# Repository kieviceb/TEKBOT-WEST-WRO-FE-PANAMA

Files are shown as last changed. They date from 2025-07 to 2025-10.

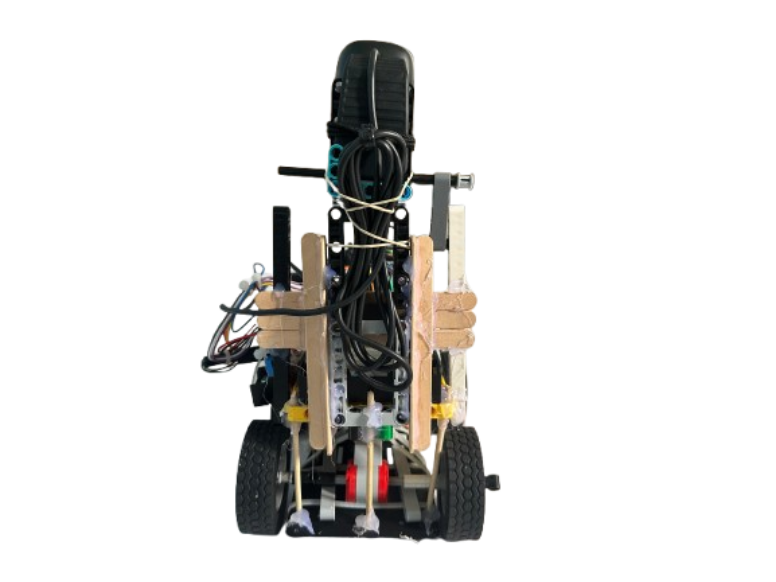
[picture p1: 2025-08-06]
vehicle photos/BACK HAM.png

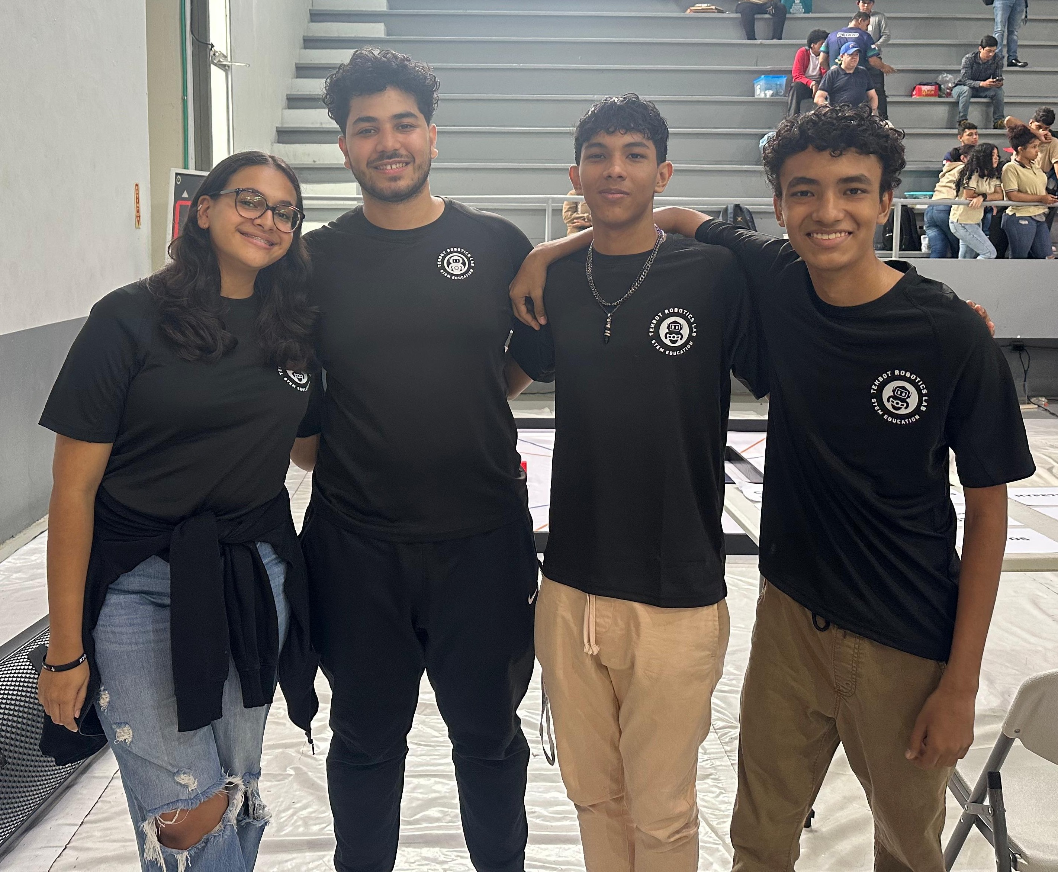
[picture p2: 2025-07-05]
team photos/TEAM PHOTOOOO.jpg

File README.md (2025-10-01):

# TEKBOT WEST's readme Bandera de Panamá
<p align="center">
  TEKBOT (1)
</p>




> [!NOTE] 
> This github repository contains many illustrative content such as images,
> gifs and video, so wait till is fully refresh to see it in its entirety.  
> 
# 🐙 Repo's folder structure/overview
```
📦 TEKBOT-WEST-WRO-FE
├── 📁 3D_printables # 3D models ready for printing robot components
├── 📁 MACHINE LEARNING MODEL # contains the trained model for the CORAL accelerator
├── 📁 schemes # Wiring and schematic diagram
├── 📁 src # Source code for robot control and challenge algorithms
├── 📁 team photos # Photos of the team 
├── 📁 vehicle photos # Pictures of the robot at different views
├── 📁 video # Video of testing competition runs
├── 📄 README.md # Main project documentation
```
---

AHHHHH_processed_by_imagy
<a href="https://github.com/kieviceb/TEKBOT-WEST-WRO-FE-PANAMA/tree/main/team%20photos">
  BEHIND THE SCREENS (2)
</a>

---
# Vehicle Photos 📸
<p align="center">
  TEKBOT (1)
</p>

Copia de BEHIND THE SCREENS

# Components 🧱
A list of all the electrical and mechanical components on the robot.

|  |  |  | 
| :---: |:---:| :---:|
|[RASPBERRY PI 5 - 8GB RAM x1](https://a.co/d/7e9fzE2)|[MICROSOFT LIFECAM HD-3000 x1](https://a.co/d/66cNAOh)|[L298N MOTOR DRIVER x1](https://www.steren.com.pa/tarjeta-para-control-de-motores-cc-l298n.html)|
|  |  |  |
|[ARDUINO NANO RP2040 CONNECT x1](https://a.co/d/hI8sZ40) |[FUNDUINO KIT CHASSIS x1](https://a.co/d/fpJSHg1)|[GEEKWORM X1202 4-Cell 5V UPS Shiled+Active Cooler H505 x1](https://a.co/d/hs9rgxH) |
|  ||  |
|[JUMPER WIRES](https://a.co/d/cw9IdJk)|[MG996R METAL GEAR SERVO x1](https://a.co/d/cRVAc0u)|[STEREN Li-ion 2800 mAh RRECHARGABLE BATTERY x7](https://www.steren.com.pa/bateria-recargable-li-ion-2800-mah-tipo-18650-1.html)|
|  ||  |
|[ULTRASONIC DISTANCE SENSOR x3](https://a.co/d/cxbABTR)|[LEGO EV3 DC MOTOR](https://ebay.us/m/6vxrYN)|[COOLING FAN x3](https://a.co/d/frwMkoA)|
|  ||  |
|[MINI BREADBOARD x1](https://a.co/d/0logMX9)|[PUSH BUTTON x1](https://a.co/d/70cfCgl)|[10K OHM RESISTOR x1](https://a.co/d/dTNRWBD)|

THE MAGIC
| :------------: |
|  |
|[GOOGLE CORAL USB EDGE TPU ACCELARATOR x1](https://a.co/d/eEklwQk)|

# ⚡Circuit diagram

Wiring diagram

# Future Engineers Challenge Overview

The **WRO 2025 Future Engineers challenge** challenges teams to design and build a fully autonomous robot capable of navigating a dynamic and randomized racetrack. Using a combination of sensors, computer vision, and advanced control algorithms, the robot must adapt to changing obstacles, follow predefined driving rules, and demonstrate precise maneuvering skills.

### 📌 Competition Format

- **🏁 Open Challenge:**  
  The robot must complete **three (3) laps** around a track where obstacles and track elements are randomly placed, requiring real-time adaptation.

- **🚦 Obstacle Challenge:**  
  The robot must detect and respond correctly to randomly positioned colored markers:  
  - 🟥 **Red signs** → Robot must drive on the right side of the lane.  
  - 🟩 **Green signs** → Robot must drive on the left side of the lane.

  After completing the laps, the robot must find a designated parking zone and perform a precise **parallel parking maneuver** within a confined space, adding an additional technical challenge.

### 📑 Documentation Requirements

Each team is required to maintain a **public GitHub repository** documenting their engineering design process, technical decisions, robot design, and source code. This encourages transparency, collaboration, and learning within the robotics community.

### 🏆 Scoring & Evaluation

Teams are evaluated based on their robot’s **accuracy**, **speed**, and the quality of their **technical documentation**. Points are awarded to teams that effectively balance performance, adaptability to randomized conditions, and innovation in their approach. This challenge promotes not only technical skills in robotics and programming but also problem-solving, teamwork, and creative engineering.
> [!WARNING]
>
> We noticed a translation misunderstanding regarding the rules, at the original english version it says
> that the robot starting within the parking lot is 7 points, but in the spanish version states that the robot should be on
> In the parking lot, not specifying if before or after the challenge is done, but taking as reference the original english version
> the robot starting on the parking lot can score 7 points.
>
meet the team (3)

---

> [!NOTE]
> For detailed rules and regulations (PANAMA ONLY), please refer to the official WRO Panama 2025 Future Engineers document:  
> [WRO 2025 Future Engineers Rules (PDF)](https://fundesteam.nyc3.cdn.digitaloceanspaces.com/FutureEngineers/WRO-2025-FE-Reglas%20Generales.pdf)

<br>

# ⚙️ Mobility Management

### Movement
- **LEGO EV3 DC Motor** driven by an L298N H-bridge on the Arduino Nano RP2040, powered by a 3×18650 Li-ion pack (≈11.1 V) for high torque.
- PWM speed control (pin D3) and direction pins (D4/D5), with automatic halt if HC-SR04 front distance < threshold.
- Receives speed & direction commands over Serial1 from the Raspberry Pi.

### Steering
- **MG996R metal-gear servo** in an Ackermann linkage for accurate, repeatable turns (pin D2).
- Servo angles (20° left, 90° center, 155° right) sent as ASCII strings over Serial1 and output via PWM.

# 🔋 Power Management

Our robot uses a streamlined power system for stable, efficient energy distribution:

- **Geekworm UPS Module**  
  All computing units (Raspberry Pi & Arduino Nano RP2040) are powered directly from the Geekworm Raspberry Pi Wide Input Voltage UPS, providing regulated 5 V output and battery backup—no external power bank needed.

- **Servo Power**  
  The MG996R steering servo draws its 5 V supply from the UPS module, ensuring stable, synchronized operation.

- **Camera and CORAL accelerator Power**  
  The Microsoft LifeCam HD-3000 and the CORAL connect via USB to the Raspberry Pi and is powered through the UPS, eliminating separate power sources.

- **DC Motor Power**  
  The L298N H-bridge and DC motor are driven by a dedicated pack of three 18650 Li-ion cells in series (≈11.1 V), delivering the higher voltage and current the motor requires.

This setup guarantees reliable power under all operating conditions.  

# 📡 Robot Communication

Our robot implements a structured communication system between its two core processing units to ensure synchronized and reliable operation:

- The **Raspberry Pi** (SBC – Single Board Computer) acts as the **master**. It is responsible for high-level tasks such as image processing, object detection, strategy decision-making, and general system coordination.

- The **Arduino Nano RP2040** (SBM – Secondary Board Microcontroller) acts as the **slave**. It is dedicated to real-time control of low-level hardware components, such as driving the servo motor, ultrasonic sensors, LEGO EV3 DC MOTOR and interpreting incoming instructions from the master.

### 🔁 Serial Communication

The two boards communicate via a **UART (Serial) interface** using the following configuration:

- **Raspberry Pi TX (GPIO 14)** → **Arduino RX (pin 1)**  
- **Raspberry Pi RX (GPIO 15)** ← **Arduino TX (pin 0)**

This full-duplex serial link enables:

- The **Raspberry Pi (master)** to send instructions like servo angles or movement triggers based on camera input.
- The **Arduino (slave)** to receive commands and execute precise control over hardware.
- **Optional feedback**: The Arduino can also send status messages or sensor feedback back to the Raspberry Pi when necessary.

This master-slave architecture promotes:

- **Modularity**, by separating high-level logic and low-level control.
- **Responsiveness**, with real-time actions handled by the microcontroller.
- **Scalability**, allowing for future hardware expansions without major rewrites.

The system is optimized for efficiency and robustness in fast-paced robotic challenges.

# 👁️ Sense and Object Detection

Our robot relies on a combination of vision (OpenCV + ML on Coral Accelerator) and ultrasonic sensing to understand its environment and make driving decisions.

## Vision System

<p align="center">
  Dataset samples
</p>

- We use the Microsoft LifeCam HD-3000 connected to the Raspberry Pi. The Pi processes the camera feed with OpenCV and a Machine Learning model accelerated by Coral to:
- Detect red and green blocks for obstacle avoidance.
- Recognize the magenta parking spot to initiate the parking routine.
- Detect black walls and estimate their distance.
- Send steering and speed commands to the Arduino Nano RP2040 over Serial.

## Ultrasonic Distance Sensing

<p align="center">
  Dataset samples
</p>

- The Arduino Nano RP2040 reads three HC-SR04 ultrasonic sensors (left, center, right) to:
    - Measure the robot’s distance from the walls.
    - Detect obstacles that may not be visible to the camera.
    - Provide redundancy and safety in case of vision failure.
    - This multi-sensor approach ensures robust performance:
    - Vision + ML handles colored block detection, parking, and wall recognition.
    - Ultrasonics provide accurate distance measurements for safety and redundancy.
      
## Machine Learning  

To improve robustness, we trained a **custom object detection model** specifically for our robot’s environment.  

<p align="center">
  Dataset samples
</p>

- The dataset was built using **Roboflow** 👉 our data set [here](https://universe.roboflow.com/tekbot-west/tekbot-west-nacional-bbbm9/dataset/2).  
- We collected and labeled images of **green/red blocks, walls, and parking spots** at different **distances, angles, and lighting conditions**, to ensure stable detection during competition with minimal calibration.  

<p align="center">
  YOLOv8 Training
</p>

- The model uses the **YOLOv8 format**, which is well-suited for real-time detection thanks to its **lightweight architecture and speed** — ideal for embedded systems.  
- Training was done in **Google Colab** using GPU acceleration.  
- Finally, we exported the trained model to **TensorFlow Lite**, optimized for the **Coral Edge TPU accelerator** on the Raspberry Pi.  

This pipeline allows the robot to run **real-time detection with low latency**, ensuring reliable navigation and obstacle avoidance.  

# ⚔️ Challenge Strategies
## Open Challenge Strategy 
- **Start Command**  
  When button is start button is pressed on the Raspberry pi sends `'s'` on Serial1 before beginning navigation.

- **Ultrasonic Sensing**  
  Continuously read left, center and right HC-SR04 sensors for obstacle distances.

- **Front Obstacle Handling**  
  If center distance ≤ FRONT_MIN, halt motor; otherwise drive at fixed PWM speed.

- **Emergency Side Avoidance**  
  If left or right distance ≤ SIDE_MIN, immediately steer hard away (servo to 150° or 20°).

- **PD Steering Control**  
  When no emergency, compute error = dR − dL and derivative, apply Kp/Kd to adjust servo within +60° -70° o deadzone around 90°.  
  This ensures smooth alignment between the two side walls.

- **Lap Counting via Encoder**  
  The IMU is no longer used. Instead, we rely on the wheel encoder:  
  - Calibration showed that **10,000 encoder counts ≈ 30 cm of travel**.  
  - Since each lap around the track is ~2 m, that corresponds to ~66,667 encoder counts.  
  - Running multiple trials from different start positions, we computed a **median value** for 3 laps.  
  - The robot stops when the encoder reading reaches this median threshold, ensuring reliable lap counting independent of curves.

- **Completion Condition**  
  Stop motor and center servo once the encoder threshold for 3 laps is reached; remain halted.

- **Serial Feedback**  
  Print encoder values, lap progress, and status messages over Serial1 for real-time monitoring.

## Obstacle Challenge Strategy 
- **Start & Exit Detection**  
  At the beginning, the robot uses **ultrasonic sensors** to measure wall distances and determine **which side it exits from the parking area**.  
  This defines its initial orientation on the track.

- **Machine Learning Object Detection**  
  Instead of simple LAB masking, we use a **YOLOv8-based model** (dataset and labels in Roboflow, trained in Google Colab and exported to TensorFlow Lite, and accelerated with Coral).  
  The model detects **red blocks, green blocks, black walls, and the magenta parking zone** in real time.  

- **Block Evasion Strategy**  
  When a block is detected:  
  - **Red →** compute a temporary target position **to the right side** and steer the robot to bypass the block.  
  - **Green →** compute a temporary target position **to the left side** for evasion.  
  The robot continues toward this evasion target until the block is cleared, then smoothly returns to its central trajectory.  

- **Lap Counting via Parking Detection**  
  Instead of counting curves or encoder ticks, the robot uses **ML detection of the magenta parking spot** as a lap marker.  
  - Each time the robot passes the parking, the counter increases by **1 lap**.  
  - After **3 passes (3 laps)**, the robot transitions to the final parking stage.  

- **PD Steering Control**  
  During normal navigation, the robot still uses **PD control** based on ultrasonic side distances (`dR - dL`) to stay centered in the lane, ensuring smooth driving even without visible blocks.  

- **Final Parking Routine**  
  Once 3 laps are completed, the robot searches for the **magenta parking zone** using ML detection.  
  Upon recognition, it executes a **parallel parking maneuver**, aligning itself precisely inside the designated parking spot.  

- **Serial Communication**  
  All steering (`S<angle>`) and motor commands are sent from the Raspberry Pi to the Arduino Nano via Serial, ensuring synchronized control.

# `</>` Into the codes (code explanations)

## 1. **Open Challenge Code — Main loop (core)**
> To keep this README concise, here we only explain the **main loop** (the core logic).  
> A complete explanation and all helper functions can be found in the [`/src`](./src) folder.  

```cpp
void loop() {

  if (!started) {
    if (Serial1.available() && Serial1.read() == 's') { //button pressed on raspberry pi sends the command to start
      started = true;
      Serial1.println("Starting navigation…");
      prevTime = micros();       // reset PD timing
      prevError = 0;
    } else {
      return;                    // stay idle until 's' is received
    }
  }
```
-  Wait for the start command over Serial1 ('s')
```cpp
 
  float dL = readUltrasonic(TRIG_LEFT,  ECHO_LEFT);   // left wall/obstacle
  float dC = readUltrasonic(TRIG_CENT,  ECHO_CENT);   // front obstacle
  float dR = readUltrasonic(TRIG_RIGHT, ECHO_RIGHT);  // right wall/obstacle

  // C) Front obstacle handling: stop if too close, otherwise run motor at fixed PWM
  if (dC <= FRONT_MIN) {
    analogWrite(ENB, 0);                 // stop motor
  } else {
    analogWrite(ENB, MOTOR_SPEED);       // forward at constant speed
  }
```
- Read distances (cm) from the 3 HC-SR04 ultrasonic sensors
```cpp
  if (dL <= SIDE_MIN_LEFT) {
    steeringServo.write(SERVO_MAX_RIGHT);  // steer right
  }
  else if (dR <= SIDE_MIN_RIGHT) {
    steeringServo.write(SERVO_MAX_LEFT);   // steer left
  }
  else {
```
 - Emergency side avoidance: steer hard away if a wall is too close
```cpp
    unsigned long now = micros();
    float dt = (now - prevTime) / 1e6;     // seconds
    prevTime = now;

    float error = dR - dL;                  // if dR>dL → robot is too close to left wall
    float dErr  = (error - prevError) / max(dt, 1e-3f);
    prevError   = error;

    int delta = constrain(int(Kp*error + Kd*dErr), -SERVO_DEADZONE, SERVO_DEADZONE);
    steeringServo.write(SERVO_CENTER + delta);  // adjust steering within limits
  }
```
- PD control for smooth centering when no emergency
```cpp
  if (encoderTicks >= ENCODER_3LAPS) {
    analogWrite(ENB, 0);                   // stop motor
    steeringServo.write(SERVO_CENTER);     // center steering
    Serial1.println("3 laps (median) reached — stopping.");
    while (true) { /* halt */ }            // end of challenge
  }
```
- Lap counting using the encoder 
Calibration: 10,000 ticks ≈ 30 cm → 1 lap (~2.0 m) ≈ 66,667 ticks
3 laps ≈ ~200,000 ticks. After several trials we set ENCODER_3LAPS to the median value.
 (encoderTicks is updated in the ISR or encoder routine outside this loop.)

## 2. **Obstacle Challenge code**

```python
ok, frame = cap.read()
if not ok:
    continue

Hf, Wf = frame.shape[:2]
y_min  = int(ROI_Y_MIN_RATIO * Hf)
x_l    = int(ROI_X_MARGIN * Wf)
x_r    = int((1.0 - ROI_X_MARGIN) * Wf)
```
read a frame and prepare ROI bands (bottom-focused + side margins)
Grab the camera frame and compute the active ROI: ignore the top band and a small margin on both sides to reduce false triggers and focus on near-field decisions.

```python
rgb = cv2.cvtColor(frame, cv2.COLOR_BGR2RGB)
inp = cv2.resize(rgb, (in_w, in_h), interpolation=cv2.INTER_LINEAR)
```
preprocess and run YOLOv8 (EdgeTPU) inference
```python
_interpreter.set_tensor(_input_details[0]['index'], np.expand_dims(inp, 0))
_interpreter.invoke()
out0 = _interpreter.get_tensor(_output_details[0]['index'])
dets = parse_yolov8_tflite(out0, _output_details[0], Wf, Hf, CONF_THRESH, NMS_IOU, _labels)
```
Convert to RGB, resize to model input, invoke TFLite + EdgeTPU, then parse outputs (dequantize, class scores, NMS) into frame-space detections.

```python
valid_L = valid_R = False
has_pklot = False

for d in dets:
    x, y, w, h, name = d['x'], d['y'], d['w'], d['h'], d['name']
    cx, cy = x + w//2, y + h//2

    in_roi = (cy >= y_min) and (x >= x_l) and (x + w <= x_r)
    near   = (cy >= int(NEAR_Y_RATIO * Hf))

    if not in_roi:
        continue

    if name == CLASS_GBLOCK and near:
        valid_L = True    # green → plan left bypass
    elif name == CLASS_RBLOCK and near:
        valid_R = True    # red → plan right bypass
    elif name == CLASS_PKLOT:
        has_pklot = True  # parking marker seen
```
scan detections to set intent flags (valid_L/valid_R) and see PKLOT
For each detection: check ROI and near-field; flag left/right evasion intent from block color; flag PKLOT for lap counting.

```python
now = time.time()
if has_pklot and (now - pklot_last_seen_t) > PKLOT_DEBOUNCE_SEC:
    pklot_last_seen_t = now
    pklot_count += 1
    if (pklot_count >= PKLOT_TARGET_COUNT) and not parking_mode:
        parking_mode = True
        if ser: ser.write(b"PARK\n")
```
debounced PKLOT counting; switch to PARK after N passes
Use a debounce window to avoid multiple counts per pass; after 3 PKLOT sightings, enter PARK mode and notify the Arduino.

```python
cooldown_ok = (now - last_cmd_t) >= COOLDOWN_SEC
streak_L = streak_L + 1 if valid_L else 0
streak_R = streak_R + 1 if valid_R else 0

send_L = cooldown_ok and (streak_L >= TRIGGER_FRAMES) and not parking_mode
send_R = cooldown_ok and (streak_R >= TRIGGER_FRAMES) and not parking_mode

if send_L or send_R:
    cmd = "PATH L" if send_L else "PATH R"
    if ser: ser.write((cmd + "\n").encode("ascii"))
    last_cmd_t = now
    streak_L = streak_R = 0
```
PATH decision: cooldown + streak of valid frames
Require a minimum streak of consecutive frames before acting, and enforce a cooldown so you send only one high-level command (PATH L/PATH R) per window. Suppress PATH when already in PARK mode.

```python
if SEND_STEER_TOWARD_WAYPOINT and aim_points:
    aim_x, aim_y = aim_points[-1]             # latest proposed lateral pass point
    sdeg = steer_towards_x(aim_x, Wf)         # map lateral error to servo [0..180]
    if ser: ser.write(f"S {sdeg}\n".encode("ascii"))
```
(optional) send direct steering toward lateral waypoint
Optionally bias steering directly toward the computed waypoint beside the block; main evasion still uses PATH L/R.

```python
cv2.line(frame, (0, y_min), (Wf, y_min), (255,255,0), 1)
cv2.rectangle(frame, (x_l, 0), (x_r, Hf), (255,255,0), 1)
cv2.putText(frame, f"PKLOT:{pklot_count}  MODE:{'PARK' if parking_mode else 'RUN'}",
            (6, Hf-8), cv2.FONT_HERSHEY_SIMPLEX, 0.6, (0,255,255), 2)

cv2.imshow("Coral YOLOv8 -> Serial", frame)
if (cv2.waitKey(1) & 0xFF) == ord('q'):
    break
```
overlays & exit handling
Draw ROI and status overlays; show the preview; quit cleanly on q.

```python
if ser:
    ser.write(b"STOP\n")
    ser.close()
cap.release()
cv2.destroyAllWindows()
```
on exit: stop and cleanup
Send a final STOP, close serial and camera, destroy windows.

## 3. **Servo control code**

- Setup function
```ino
void setup() {
  miServo.attach(pinServo);
  Serial1.begin(9600);
  Serial.begin(9600);
  delay(1000);

  Serial.println("Send angle (0 to 180) via Serial1 to move the servo.");
  miServo.write(90);
}
```
The servo is attached to the specified pin. UART serial communication (Serial1) is started at 9600 baud to talk with the Raspberry Pi, and USB serial (Serial) is started for debugging. The program waits one second for stability. A message with instructions is printed to the debug monitor. The servo is initialized at center position (90 degrees).

- Loop function: reading and processing commands
```ino
void loop() {
  while (Serial1.available() > 0) {
    char c = Serial1.read();

    if (c == '\n' || c == '\r') {
      comando.trim();

      if (comando.length() > 0) {
        int angulo = comando.toInt();

        if (angulo >= 0 && angulo <= 180) {
          miServo.write(angulo);
          Serial.print("Servo moved to ");
          Serial.print(angulo);
          Serial.println(" degrees");
        } else {
          Serial.println("Angle out of range (0–180)");
        }
      }

      comando = "";
    } else {
      comando += c;
    }
  }
}
```
The code reads incoming characters from the UART serial buffer one by one. It accumulates them into a command string until it detects a newline or carriage return character, signaling the end of a command. Then it trims whitespace from the command. If the command is not empty, it converts the string to an integer representing the servo angle. It checks if the angle is between 0 and 180 degrees. If valid, it moves the servo to that angle and prints a confirmation message. If invalid, it prints an error message. After processing, it clears the command buffer to prepare for the next command and continues looping.

## 4. **Run code when the raspberry turns on**
- Import libraries and modules
```python
from gpiozero import Button
from signal import pause
import subprocess
```
The script imports the Button class from gpiozero to handle GPIO pin inputs on the Raspberry Pi. The pause function from the signal module is imported to keep the script running and listening for events. The subprocess module allows the script to run external programs or scripts.

- Initialize button on GPIO pin 16
```python
boton = Button(16)
```
A Button object is created and linked to GPIO pin 16, which is physically connected to a push button on the Raspberry Pi. This button will trigger running the robot’s main program.

- Define function to run the main program
```python
def ejecutar_programa():
    print("Button pressed! Running the main program...")
    subprocess.run(["python3", "/home/frankie/WRO_Ingeniero/execute.py"])
```
This function runs when the button is pressed. It prints a message to the terminal indicating the button press and then uses subprocess.run to execute another Python script (otracosaahi.py), which is the robot’s main control program. The path must be correct and the script must be executable.

- Link button press event to the function
```python
boton.when_pressed = ejecutar_programa
```
The button’s press event is connected to the ejecutar_programa function. When the button is pressed, this function will be called automatically.

- Indicate readiness and keep script running
```python
print("Waiting for the button to be pressed...")
pause()
```
Prints a message to inform the user that the system is ready and listening for the button press. The pause() function keeps the script running indefinitely so it can detect the button press event; without it, the script would exit immediately.

# 🎥 Video demonstration
TEKBOT (https://youtu.be/VGku5C4htFQ?si=9HICP8p2Be4NuSKb)
TEKBOT(2) (https://youtu.be/uQNMZddFvvI?si=1SfpjZH-YJ5O9Mvj)
---
**Stay tuned for updates as we continue to improve our robot's performance and capabilities!**

# References
- https://docs.ultralytics.com/models/yolov8/
- https://colab.research.google.com/github/roboflow/notebooks/blob/main/notebooks/train-yolov8-object-detection-on-custom-dataset.ipynb
- https://nerdvana.ro/wro-fe/
- https://markdownlivepreview.com/
- https://docs.opencv.org/3.4/da/d97/tutorial_threshold_inRange.html

# Shout-Outs

A huge thank you to everyone who made this project possible:

- **The Sutherland Family**  
  For sharing their technical know-how, sourcing crucial parts, and helping with all of our 3D printing needs.

- **Ericka’s Family**  
  For opening up their living room as our track space and pitching in to build the surrounding walls.

- **The Hidalgo Family**  
  For generously donating the printed track mat that serves as our competition surface.

- **Diego’s Family**  
  For welcoming us into their home and providing a comfortable space for our team meetings and build sessions.

We couldn’t have done it without your support—thank you for being an integral part of our journey!

# 📜 License

MIT License

Copyright (c) 2025 Ericka Ceballos

Permission is hereby granted, free of charge, to any person obtaining a copy
of this software and associated documentation files (the "Software"), to deal
in the Software without restriction, including without limitation the rights
to use, copy, modify, merge, publish, distribute, sublicense, and/or sell
copies of the Software, and to permit persons to whom the Software is
furnished to do so, subject to the following conditions:

The above copyright notice and this permission notice shall be included in all
copies or substantial portions of the Software.

THE SOFTWARE IS PROVIDED "AS IS", WITHOUT WARRANTY OF ANY KIND, EXPRESS OR
IMPLIED, INCLUDING BUT NOT LIMITED TO THE WARRANTIES OF MERCHANTABILITY,
FITNESS FOR A PARTICULAR PURPOSE AND NONINFRINGEMENT. IN NO EVENT SHALL THE
AUTHORS OR COPYRIGHT HOLDERS BE LIABLE FOR ANY CLAIM, DAMAGES OR OTHER
LIABILITY, WHETHER IN AN ACTION OF CONTRACT, TORT OR OTHERWISE, ARISING FROM,
OUT OF OR IN CONNECTION WITH THE SOFTWARE OR THE USE OR OTHER DEALINGS IN THE
SOFTWARE.

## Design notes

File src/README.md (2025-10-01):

## 1. **Open Challenge code**
```ino
#include <Servo.h>  // Include the Servo library to control a hobby servo motor

// —— ULTRASONIC SENSOR PINOUT ——  
// These pins are connected to three ultrasonic distance sensors: left, center, and right
const int TRIG_LEFT   = 6;   // Trigger pin for the left ultrasonic sensor
const int ECHO_LEFT   = 7;   // Echo pin for the left ultrasonic sensor
const int TRIG_CENT   = 8;   // Trigger pin for the center ultrasonic sensor
const int ECHO_CENT   = 9;   // Echo pin for the center ultrasonic sensor
const int TRIG_RIGHT  = 10;  // Trigger pin for the right ultrasonic sensor
const int ECHO_RIGHT  = 11;  // Echo pin for the right ultrasonic sensor

// —— ACTUATOR PINOUT ——  
// Pins to control the servo (steering) and a motor (via H-bridge L298N)
const int SERVO_PIN      = 2;   // Servo control pin
const int ENB            = 3;   // Motor speed pin (PWM)
const int IN3            = 4;   // Motor direction pin
const int IN4            = 5;   // Motor direction pin

// —— CONTROL PARAMETERS (PD controller) ——  
const float Kp           = 0.5;   // Proportional gain for PD control
const float Kd           = 0.1;   // Derivative gain for PD control
float prevError          = 0;     // Previous error value for derivative calculation
unsigned long prevTime   = 0;     // Previous time in microseconds for derivative calculation

// —— SAFETY THRESHOLDS IN CM ——  
const float SIDE_MIN_LEFT   = 17.0;  // Minimum allowed distance on left side
const float SIDE_MIN_RIGHT  = 18.5;  // Minimum allowed distance on right side
const float FRONT_MIN       = 25.0;  // Minimum allowed distance in front

// —— SERVO LIMITS ——  
const int SERVO_CENTER      = 90;   // Center position of servo (straight)
const int SERVO_MAX_LEFT    = 20;   // Maximum left steering angle
const int SERVO_MAX_RIGHT   = 150;  // Maximum right steering angle
const int SERVO_DEADZONE    = 60;   // Maximum deviation allowed for PD output

// —— FIXED MOTOR SPEED ——  
const int MOTOR_SPEED       = 200;  // PWM value for motor speed (0–255)

Servo steeringServo;  // Create Servo object for steering

// ==================== ENCODER SETUP ====================
// Pins for quadrature encoder
const uint8_t ENC_B = 12;   // Encoder channel B
const uint8_t ENC_A = 13;   // Encoder channel A

volatile long encoderCount = 0;    // Counter for encoder ticks (volatile because updated in ISR)
volatile uint8_t prevAB = 0;       // Previous state of encoder channels

// Quadrature table for determining rotation direction
int8_t quad_table[16] = {
  0, -1, +1,  0,
  +1, 0,  0, -1,
  -1, 0,  0, +1,
   0, +1, -1,  0
};

const long STOP_COUNTS = 2000;  // Encoder count at which the robot must stop

// Helper function to read current state of encoder channels A and B
inline uint8_t readAB() {
  return (digitalRead(ENC_A) << 1) | (digitalRead(ENC_B));
}

// Interrupt service routine (ISR) for encoder updates
void isr_any() {
  uint8_t curr = readAB();               // Read current encoder state
  uint8_t idx  = ((prevAB << 2) | curr) & 0x0F; // Combine previous and current state
  encoderCount += quad_table[idx];       // Update encoder count according to table
  prevAB = curr;                         // Store current state for next ISR
}
// =================================================

// —— START FLAG ——  
bool startFlag = false;  // Flag to indicate when robot should start moving

void setup() {
  // —— ENCODER SETUP ——  
  pinMode(ENC_A, INPUT_PULLUP);  // Enable internal pull-up resistor
  pinMode(ENC_B, INPUT_PULLUP);  // Enable internal pull-up resistor
  prevAB = readAB();             // Initialize previous state
  attachInterrupt(digitalPinToInterrupt(ENC_A), isr_any, CHANGE); // Interrupt on channel A
  attachInterrupt(digitalPinToInterrupt(ENC_B), isr_any, CHANGE); // Interrupt on channel B

  // —— ULTRASONIC SENSOR SETUP ——  
  pinMode(TRIG_LEFT,   OUTPUT);
  pinMode(ECHO_LEFT,   INPUT);
  pinMode(TRIG_CENT,   OUTPUT);
  pinMode(ECHO_CENT,   INPUT);
  pinMode(TRIG_RIGHT,  OUTPUT);
  pinMode(ECHO_RIGHT,  INPUT);

  // —— SERVO AND MOTOR SETUP ——  
  steeringServo.attach(SERVO_PIN);       // Attach servo object to pin
  steeringServo.write(SERVO_CENTER);     // Initialize servo to center position

  pinMode(ENB, OUTPUT);                  // Motor speed control
  pinMode(IN3, OUTPUT);                  // Motor direction
  pinMode(IN4, OUTPUT);                  // Motor direction
  digitalWrite(IN3, HIGH);               // Set initial direction forward
  digitalWrite(IN4, LOW);

  prevTime = micros();                   // Initialize timing for PD derivative

  // —— SERIAL COMMUNICATION ——  
  Serial1.begin(115200);   // Serial1 for Raspberry Pi communication
  Serial.begin(115200);    // USB serial for debugging
  while (!Serial) {}       // Wait for serial port to be ready
  Serial.println(F("System ready, waiting for 's' from RPi..."));
}

void loop() {
  // —— SERIAL1 LISTENING ——  
  if (Serial1.available()) {
    char cmd = Serial1.read();  // Read command from Raspberry Pi
    if (cmd == 's') {           // If 's' is received, start robot
      startFlag = true;
      encoderCount = 0;         // Reset encoder when starting
      Serial.println(F("✔ Start received from RPi"));
    }
  }

  // —— WAIT FOR START FLAG ——  
  if (!startFlag) {
    analogWrite(ENB, 0);              // Stop motor
    steeringServo.write(SERVO_CENTER); // Center steering
    delay(50);                          // Short delay to avoid busy loop
    return;
  }

  // —— READ ENCODER ——  
  noInterrupts();           // Temporarily disable interrupts to safely read shared variable
  long c = encoderCount;    // Copy encoder count
  interrupts();             // Re-enable interrupts

  if (c >= STOP_COUNTS) {   // If encoder count exceeds limit
    analogWrite(ENB, 0);               // Stop motor
    steeringServo.write(SERVO_CENTER); // Center steering
    Serial.println(F("🚨 STOP: encoder limit reached 🚨"));
    delay(100);
    return;
  }

  // —— PD CONTROL ——  
  float dL = readUltrasonic(TRIG_LEFT,  ECHO_LEFT);   // Left distance
  float dC = readUltrasonic(TRIG_CENT,  ECHO_CENT);   // Center distance
  float dR = readUltrasonic(TRIG_RIGHT, ECHO_RIGHT);  // Right distance

  // —— FRONT OBSTACLE CHECK ——  
  if (dC <= FRONT_MIN) {          // If something is too close in front
    analogWrite(ENB, 0);          // Stop motor
  } else {
    analogWrite(ENB, MOTOR_SPEED); // Move forward at fixed speed
  }

  // —— SIDE OBSTACLE AVOIDANCE ——  
  if (dL <= SIDE_MIN_LEFT) {                   // Too close to left wall
    steeringServo.write(SERVO_MAX_RIGHT);      // Steer right
  }
  else if (dR <= SIDE_MIN_RIGHT) {            // Too close to right wall
    steeringServo.write(SERVO_MAX_LEFT);      // Steer left
  }
  else {
    // —— PD STEERING CONTROL ——  
    unsigned long now = micros();           // Current time
    float dt = (now - prevTime) / 1e6;     // Time difference in seconds
    prevTime = now;

    float error  = dR - dL;                 // Difference between right and left distances
    float dError = (error - prevError) / dt; // Derivative of error
    prevError    = error;

    float control = Kp * error + Kd * dError;  // PD control signal
    int delta = constrain(int(control), -SERVO_DEADZONE, SERVO_DEADZONE); // Limit deviation
    steeringServo.write(constrain(SERVO_CENTER + delta, SERVO_MAX_LEFT, SERVO_MAX_RIGHT)); // Set servo
  }

  delay(50); // Small delay to control loop speed
}

// —— ULTRASONIC SENSOR READING FUNCTION ——  
float readUltrasonic(int trigPin, int echoPin) {
  digitalWrite(trigPin, LOW);               // Ensure trigger pin is LOW
  delayMicroseconds(2);                     // Short delay
  digitalWrite(trigPin, HIGH);              // Send pulse
  delayMicroseconds(10);                    // 10us HIGH pulse
  digitalWrite(trigPin, LOW);               // End pulse
  long duration = pulseIn(echoPin, HIGH, 30000); // Measure pulse duration (max 30ms)
  if (duration == 0) return 300;            // Timeout → treat as very far
  return duration * 0.0343 / 2.0;          // Convert duration to cm
}

```
## 2. **Obstacle Challenge code**
Import libraries
```python
import cv2
import numpy as np
import serial
import time
from gpiozero import Motor, PWMOutputDevice
```
Handles camera access, image processing, numerical operations, motor control, and serial communication with Arduino.

- Serial connection setup
```python
arduino = serial.Serial("/dev/serial0", baudrate=9600, timeout=1)
time.sleep(2)
```
Establishes a UART connection between the Raspberry Pi and Arduino with a short delay to stabilize communication.

- Motor and speed setup
```python
motor = Motor(forward=20, backward=21)
velocidad = PWMOutputDevice(12)
velocidad.value = 0.85
```
Configures GPIO pins for motor direction and sets PWM speed to 85%.

- Camera setup
```python
cap = cv2.VideoCapture(0)
cv2.namedWindow("Vista Completa", cv2.WINDOW_NORMAL)
cv2.resizeWindow("Vista Completa", 800, 600)
```
Initializes the camera and creates a display window for visual feedback.

- Control and state variables
```python
lineas_detectadas = 0
umbral_linea = 1000
umbral_bloque = 800
linea_detectada = False
girando = False
direccion_giro = None

red_limit_x = 170
green_limit_x = 470
```
Tracks the state of line detection, block turns, and defines positional thresholds to determine when a block has passed.

- Helper function to find mask centroid
```python
def obtener_centro(mask):
    M = cv2.moments(mask)
    if M["m00"] != 0:
        cx = int(M["m10"] / M["m00"])
        return cx
    return None
```
Calculates the X-coordinate of the centroid of a binary mask. Used to know where a block is in the frame.

- Frame capture
```python
ret, frame = cap.read()
if not ret:
    continue
```
Reads the current frame from the camera. If the read fails, the loop skips to the next iteration.

- Block detection (red and green)
```python
roi_bloques = frame[200:320, :]
hsv_bloques = cv2.cvtColor(roi_bloques, cv2.COLOR_BGR2HSV)

# Red mask
lower_red1 = np.array([0, 120, 120])
upper_red1 = np.array([10, 255, 255])
lower_red2 = np.array([160, 120, 120])
upper_red2 = np.array([179, 255, 255])
mask_red = cv2.inRange(hsv_bloques, lower_red1, upper_red1) | cv2.inRange(hsv_bloques, lower_red2, upper_red2)

# Green mask
lower_green = np.array([85, 100, 100])
upper_green = np.array([100, 255, 255])
mask_green = cv2.inRange(hsv_bloques, lower_green, upper_green)

area_rojo = cv2.countNonZero(mask_red)
area_green = cv2.countNonZero(mask_green)
cx_rojo = obtener_centro(mask_red)
cx_green = obtener_centro(mask_green)
```
Detects red and green blocks based on HSV color ranges and calculates their positions and areas.

- Black line detection
```python
roi_nav = frame[160:280, :]
gray = cv2.cvtColor(roi_nav, cv2.COLOR_BGR2GRAY)
_, mask_black = cv2.threshold(gray, 50, 255, cv2.THRESH_BINARY_INV)

width = mask_black.shape[1]
third = width // 3
left_black = cv2.countNonZero(mask_black[:, 0:third])
center_black = cv2.countNonZero(mask_black[:, third:2*third])
right_black = cv2.countNonZero(mask_black[:, 2*third:3*third])
```
Uses a grayscale region to isolate the black navigation line and counts how many black pixels are in each section.

- Turning and navigation logic
```python
direction = 'C'
```
Initial direction is centered.

If turning based on block previously detected:
```python
if girando:
    if direccion_giro == 'R':
        if cx_rojo is not None and cx_rojo <= red_limit_x:
            girando = False
            direccion_giro = None
        elif right_black > 300:
            direction = 'C'
        else:
            direction = 'R'
    elif direccion_giro == 'L':
        if cx_green is not None and cx_green >= green_limit_x:
            girando = False
            direccion_giro = None
        elif left_black > 300:
            direction = 'C'
        else:
            direction = 'L'
```
If not currently turning:
```python
else:
    if area_rojo > umbral_bloque and cx_rojo is not None:
        direccion_giro = 'R'
        girando = True
        direction = 'R'
    elif area_green > umbral_bloque and cx_green is not None:
        direccion_giro = 'L'
        girando = True
        direction = 'L'
    else:
        min_black = min(left_black, center_black, right_black)
        if min_black == center_black:
            direction = 'C'
        elif min_black == left_black:
            direction = 'L'
        elif min_black == right_black:
            direction = 'R'
```
Controls the robot’s turning behavior based on detected blocks and black line regions.

- Orange line detection for stopping
```python
roi_linea = frame[400:480, :]
hsv = cv2.cvtColor(roi_linea, cv2.COLOR_BGR2HSV)
lower_orange = np.array([10, 150, 150])
upper_orange = np.array([25, 255, 255])
mask_linea = cv2.inRange(hsv, lower_orange, upper_orange)
area_linea = cv2.countNonZero(mask_linea)

if area_linea > umbral_linea and not linea_detectada and lineas_detectadas < 12:
    lineas_detectadas += 1
    linea_detectada = True
    time.sleep(1)

if area_linea <= umbral_linea:
    linea_detectada = False

if lineas_detectadas >= 12:
    direction = 'S'
    motor.stop()
else:
    motor.forward()
```
Counts the number of orange lines the robot crosses. Stops movement after 12 detections.

- Send servo angle to Arduino
```python
if direction == 'L':
    angulo = '58'
elif direction == 'C':
    angulo = '90'
elif direction == 'R':
    angulo = '120'
else:
    angulo = '90'

arduino.write((angulo + "\n").encode())
```
Maps the movement direction to a specific servo angle and sends the command to the Arduino for steering.

## 3. **Servo control code**
- Include libraries
```ino
#include <Servo.h>
#include <math.h>
```
The Servo.h library is included to control servo motors. math.h is included for compatibility but is not directly used in this code.

- Variable and object declarations
```ino
Servo miServo;
int pinServo = 2;
String comando = "";
unsigned long ultimoEnvio = 0;
const unsigned long intervalo = 100;
```
The miServo object is created to control the servo motor. pinServo sets the pin connected to the servo signal wire. The comando variable stores incoming serial commands as a string. ultimoEnvio and intervalo are reserved for timing tasks but are unused here.

- Setup function
```ino
void setup() {
  miServo.attach(pinServo);
  Serial1.begin(9600);
  Serial.begin(9600);
  delay(1000);

  Serial.println("Send angle (0 to 180) via Serial1 to move the servo.");
  miServo.write(90);
}
```
The servo is attached to the specified pin. UART serial communication (Serial1) is started at 9600 baud to talk with the Raspberry Pi, and USB serial (Serial) is started for debugging. The program waits one second for stability. A message with instructions is printed to the debug monitor. The servo is initialized at center position (90 degrees).

- Loop function: reading and processing commands
```ino
void loop() {
  while (Serial1.available() > 0) {
    char c = Serial1.read();

    if (c == '\n' || c == '\r') {
      comando.trim();

      if (comando.length() > 0) {
        int angulo = comando.toInt();

        if (angulo >= 0 && angulo <= 180) {
          miServo.write(angulo);
          Serial.print("Servo moved to ");
          Serial.print(angulo);
          Serial.println(" degrees");
        } else {
          Serial.println("Angle out of range (0–180)");
        }
      }

      comando = "";
    } else {
      comando += c;
    }
  }
}
```
The code reads incoming characters from the UART serial buffer one by one. It accumulates them into a command string until it detects a newline or carriage return character, signaling the end of a command. Then it trims whitespace from the command. If the command is not empty, it converts the string to an integer representing the servo angle. It checks if the angle is between 0 and 180 degrees. If valid, it moves the servo to that angle and prints a confirmation message. If invalid, it prints an error message. After processing, it clears the command buffer to prepare for the next command and continues looping.

## 4. **Run code when the raspberry turns on**
- Import libraries and modules
```python
from gpiozero import Button
from signal import pause
import subprocess
```
The script imports the Button class from gpiozero to handle GPIO pin inputs on the Raspberry Pi. The pause function from the signal module is imported to keep the script running and listening for events. The subprocess module allows the script to run external programs or scripts.

- Initialize button on GPIO pin 16
```python
boton = Button(16)
```
A Button object is created and linked to GPIO pin 16, which is physically connected to a push button on the Raspberry Pi. This button will trigger running the robot’s main program.

- Define function to run the main program
```python
def ejecutar_programa():
    print("Button pressed! Running the main program...")
    subprocess.run(["python3", "/home/diego/WRO_Ingeniero/otracosaahi.py"])
```
This function runs when the button is pressed. It prints a message to the terminal indicating the button press and then uses subprocess.run to execute another Python script (otracosaahi.py), which is the robot’s main control program. The path must be correct and the script must be executable.

- Link button press event to the function
```python
boton.when_pressed = ejecutar_programa
```
The button’s press event is connected to the ejecutar_programa function. When the button is pressed, this function will be called automatically.

- Indicate readiness and keep script running
```python
print("Waiting for the button to be pressed...")
pause()
```
Prints a message to inform the user that the system is ready and listening for the button press. The pause() function keeps the script running indefinitely so it can detect the button press event; without it, the script would exit immediately.

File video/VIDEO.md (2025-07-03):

# 🎥 **Video demonstration**
Click down below for the demonstration of the first round of our robot.

[CLICK HERE!](https://youtu.be/aBIIU7W57JA?si=Zv62mgVx7OuttPh0)

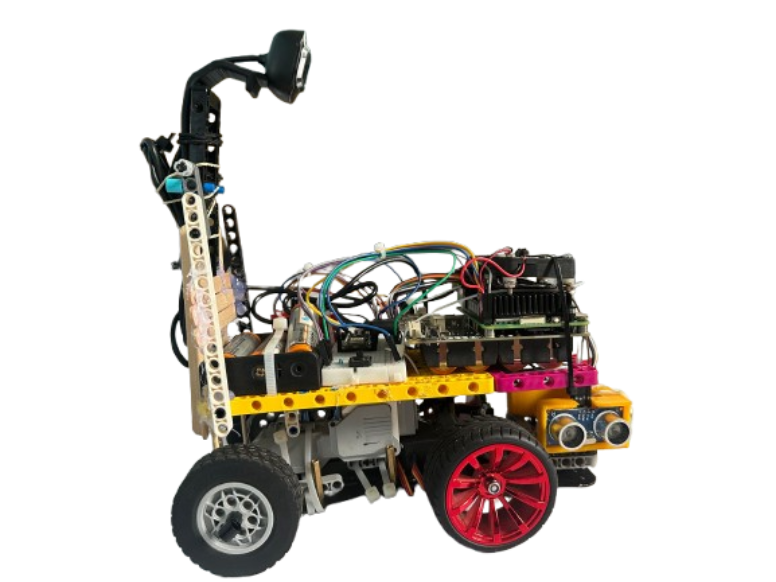
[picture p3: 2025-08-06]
vehicle photos/RIGHT HAM.png

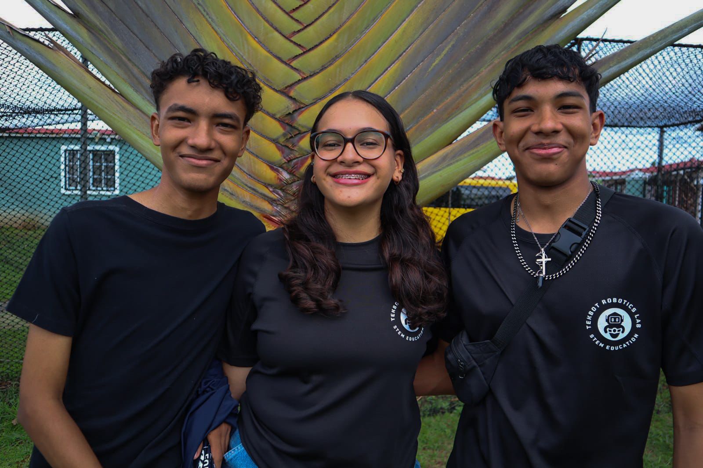
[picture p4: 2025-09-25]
team photos/TEAM PHOTO.jpg

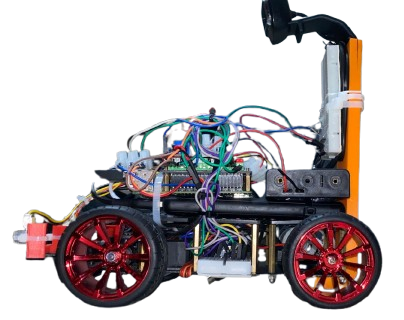
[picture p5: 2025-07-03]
vehicle photos/First prototype/LEFT.png

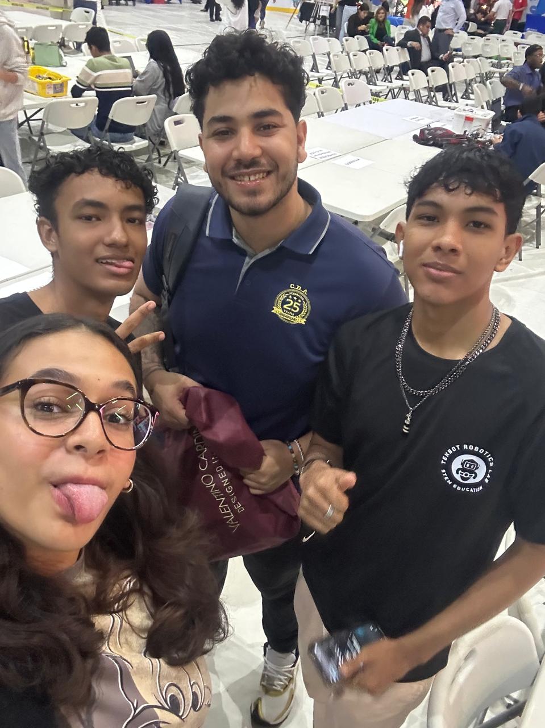
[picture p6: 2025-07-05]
team photos/funny photooo.jpg

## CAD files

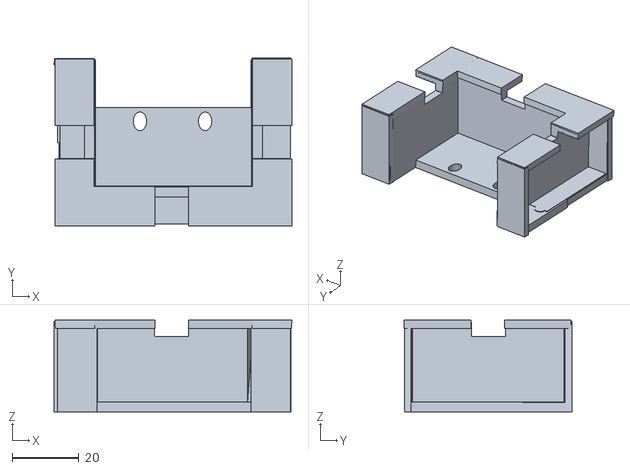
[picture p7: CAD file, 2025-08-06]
3D_printables/ultrasonic_sensors_front_base.stl
71.2 x 50.2 x 27.5

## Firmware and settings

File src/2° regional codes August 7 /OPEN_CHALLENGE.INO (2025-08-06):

#include <Wire.h>
#include <MPU6050.h>
#include <Servo.h>

// —— PINOUT ——
// HC-SR04 Ultrasonic Sensors
const int TRIG_LEFT   = 6;   // Left trigger pin (D6)
const int ECHO_LEFT   = 7;   // Left echo pin    (D7)
const int TRIG_CENT   = 8;   // Center trigger   (D8)
const int ECHO_CENT   = 9;   // Center echo      (D9)
const int TRIG_RIGHT  = 10;  // Right trigger    (D10)
const int ECHO_RIGHT  = 11;  // Right echo       (D11)

// Actuators
const int SERVO_PIN      = 2;   // Steering servo (D2)
const int ENB            = 3;   // Motor enable PWM (D3)
const int IN3            = 4;   // Motor direction (D4)
const int IN4            = 5;   // Motor direction (D5)

// —— CONTROL PARAMETERS —— 
const float Kp           = 0.5; // Proportional gain
const float Kd           = 0.1; // Derivative gain

// —— SAFETY THRESHOLDS (cm) —— 
const float SIDE_MIN_LEFT   = 17.0;  // Min distance to left wall
const float SIDE_MIN_RIGHT  = 16.0;  // Min distance to right wall
const float FRONT_MIN       = 16.0;  // Min front distance

// —— SERVO LIMITS —— 
const int SERVO_CENTER      = 90;   // Center position
const int SERVO_MAX_LEFT    = 60;   // Max left turn
const int SERVO_MAX_RIGHT   = 120;  // Max right turn
const int SERVO_DEADZONE    = 30;   // ±30° around center for PD

// —— MOTOR SPEED ——  
const int MOTOR_SPEED       = 200;  // Fixed PWM (0–255)

Servo steeringServo;
MPU6050 imu;                     // MPU6050 IMU object

// State variables
bool started       = false;     // Has 's' been received?
int curveCount     = 0;         // Number of curves detected
bool turning       = false;     // Are we currently in a turn?
float prevError    = 0;         
unsigned long prevTime = 0;

void setup() {
  // Begin Serial1 for start command
  Serial1.begin(115200);
  Serial1.println("Waiting for 's' on Serial1 to start...");

  // Initialize IMU (MPU6050)
  Wire.begin();
  imu.initialize();
  if (!imu.testConnection()) {
    Serial1.println("IMU connection failed!");
    while (true); // Halt if IMU is missing
  }
  Serial1.println("IMU initialized.");

  // Initialize ultrasonic sensor pins
  pinMode(TRIG_LEFT, OUTPUT);
  pinMode(ECHO_LEFT, INPUT);
  pinMode(TRIG_CENT, OUTPUT);
  pinMode(ECHO_CENT, INPUT);
  pinMode(TRIG_RIGHT, OUTPUT);
  pinMode(ECHO_RIGHT, INPUT);

  // Initialize and center steering servo
  steeringServo.attach(SERVO_PIN);
  steeringServo.write(SERVO_CENTER);

  // Initialize DC motor (H-bridge)
  pinMode(ENB, OUTPUT);
  pinMode(IN3, OUTPUT);
  pinMode(IN4, OUTPUT);
  digitalWrite(IN3, HIGH);  // Forward direction
  digitalWrite(IN4, LOW);

  prevTime = micros();
}

void loop() {
  // ——— Wait for 's' on Serial1 to begin ———
  if (!started) {
    if (Serial1.available() > 0 && Serial1.read() == 's') {
      started = true;
      Serial1.println("Start command received. Running...");
    } else {
      return; // Do nothing until start
    }
  }

  // ——— 1) Read ultrasonic distances ———
  float dL = readUltrasonic(TRIG_LEFT,  ECHO_LEFT);
  float dC = readUltrasonic(TRIG_CENT,  ECHO_CENT);
  float dR = readUltrasonic(TRIG_RIGHT, ECHO_RIGHT);

  // ——— 2) Front obstacle check ———
  if (dC <= FRONT_MIN) {
    analogWrite(ENB, 0);  // Too close → stop motor
  } else {
    analogWrite(ENB, MOTOR_SPEED);  // Otherwise fixed speed
  }

  // ——— 3) Emergency side avoidance ———
  if (dL <= SIDE_MIN_LEFT) {
    // Left wall too close → turn right hard
    steeringServo.write(SERVO_MAX_RIGHT);
  }
  else if (dR <= SIDE_MIN_RIGHT) {
    // Right wall too close → turn left hard
    steeringServo.write(SERVO_MAX_LEFT);
  }
  else {
    // ——— 4) PD steering control ———
    unsigned long now = micros();
    float dt = (now - prevTime) / 1e6;
    prevTime = now;

    float error  = dR - dL;
    float dError = (error - prevError) / dt;
    prevError    = error;

    float control = Kp * error + Kd * dError;
    int delta = constrain(int(control), -SERVO_DEADZONE, SERVO_DEADZONE);
    steeringServo.write(SERVO_CENTER + delta);
  }

  // ——— 5) Turn detection using IMU ———
  // Read gyroscope Z axis (°/s)
  float gyroZ = imu.getRotationZ() / 131.0;
  const float TURN_THRESHOLD = 30.0; // °/s threshold for a turn

  if (abs(gyroZ) > TURN_THRESHOLD) {
    if (!turning) {
      turning = true;         // We just started a turn
      curveCount++;
      Serial1.print("Curve #");
      Serial1.println(curveCount);
    }
  } else {
    turning = false;          // No longer turning
  }

  // ——— 6) Stop after 12 curves ———
  if (curveCount >= 12) {
    // Halt motor and center steer
    analogWrite(ENB, 0);
    steeringServo.write(SERVO_CENTER);
    Serial1.println("12 curves detected. Robot stopped.");
    while (true) {
      // Do nothing — robot remains stopped
    }
  }

  delay(50);  // ~20 Hz loop
}

// Generic HC-SR04 reading function (returns cm)
float readUltrasonic(int trigPin, int echoPin) {
  digitalWrite(trigPin, LOW);
  delayMicroseconds(2);
  digitalWrite(trigPin, HIGH);
  delayMicroseconds(10);
  digitalWrite(trigPin, LOW);
  long duration = pulseIn(echoPin, HIGH, 30000);
  if (duration == 0) return 300;               // No echo: assume far
  return duration * 0.0343 / 2.0;              // Convert to cm
}

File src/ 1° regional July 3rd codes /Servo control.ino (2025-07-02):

#include <Servo.h>   // Library to control servo motors
#include <math.h>    // Included for compatibility (not used directly here)

Servo miServo;             // Create servo motor object
int pinServo = 2;          // Define the pin connected to the servo signal wire
String comando = "";       // Buffer for incoming serial commands

unsigned long ultimoEnvio = 0;
const unsigned long intervalo = 100;  // (Reserved) Time interval for potential future tasks

void setup() {
  miServo.attach(pinServo);          // Attach the servo to its control pin
  Serial1.begin(9600);               // Serial communication with Raspberry Pi (UART)
  Serial.begin(9600);                // USB serial monitor for debugging
  delay(1000);                       // Wait for everything to stabilize

  Serial.println("Send angle (0 to 180) via Serial1 to move the servo.");
  miServo.write(90);                 // Initialize servo in the center (90°)
}

void loop() {
  // --- Read and process commands from Raspberry Pi ---
  while (Serial1.available() > 0) {
    char c = Serial1.read();         // Read one character at a time

    if (c == '\n' || c == '\r') {    // Command ends when newline or carriage return is received
      comando.trim();                // Remove whitespace or extra characters

      if (comando.length() > 0) {
        int angulo = comando.toInt();  // Convert the command to an integer angle

        // Check if the angle is valid (between 0° and 180°)
        if (angulo >= 0 && angulo <= 180) {
          miServo.write(angulo);     // Move the servo to the requested angle
          Serial.print("Servo moved to ");
          Serial.print(angulo);
          Serial.println(" degrees");
        } else {
          Serial.println("Angle out of range (0–180)");
        }
      }

      comando = "";                  // Clear the command string
    } else {
      comando += c;                  // Build the command character by character
    }
  }
}

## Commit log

2025-05-27 Create diagramas, esquematico y el otro
2025-06-14 Rename soporte de la camara.stl to webcam support.stl
    [webcam support.stl]
2025-06-27 Add the Wiring Diagram, the Wiring Esquematic and the Fritzing File
    [2025 WRO FUTURE ENGINEER TEKBOT WEST.fzz]
2025-07-02 Create Servo control.ino
2025-07-03 Rename shematic diagram_schem.png to schematic diagram IMGpng
2025-07-03 Rename scehamtic diagram.fzz to schematic diagram.fzz
    [schematic diagram.fzz]
2025-07-09 Rename src/Servo control.ino to src/1° regional july 3rd codes/Servo control.ino
2025-07-09 Rename Servo control.ino to Servo control.ino
2025-08-06 Rename soporte_delantero_4_ultrasonico (1).stl to 3D_printables/ultrasonci_sensors_front_base.stl
    [ultrasonci_sensors_front_base.stl]
2025-08-06 Rename vehicle photos/BACK.png to vehicle photos/First prototype/1BACK.png
2025-08-06 Rename vehicle photos/BOTTOM.png to vehicle photos/First prototype/BOTTOM.png
2025-08-06 Rename vehicle photos/FRONT.png to vehicle photos/First prototype/FRONT.png
2025-08-06 Rename vehicle photos/LEFT.png to vehicle photos/First prototype/LEFT.png
2025-08-06 Rename vehicle photos/TOP.png to vehicle photos/First prototype/TOP.png
2025-08-06 Rename vehicle photos/RIGHT.png to vehicle photos/First prototype/RIGHT.png
